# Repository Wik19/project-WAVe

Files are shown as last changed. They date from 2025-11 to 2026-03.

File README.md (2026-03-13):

# project-WAVe: Vibroacoustic Measurement System for Flapping-Wing Drones

## Overview
**project-WAVe** (Wing Acoustic & Vibroacoustic Experiment) is a custom wireless measurement system designed for flapping-wing drones. This repository contains the hardware design, firmware, and software for a high-fidelity data acquisition platform, specifically tailored as a lightweight expansion deck for the [Flapper Nimble+](https://flapper-drones.com/product/flapper-nimble/) platform.

It serves as a foundation for collecting large-scale vibroacoustic datasets required to develop future machine learning-based Fault Detection and Diagnosis (FDD) algorithms.

## Key Features
* **Miniaturized Custom Hardware**: A custom 4-layer PCB (25.2 x 27.3 mm) designed to fit the standard Bitcraze Crazyflie expansion deck footprint.
* **High-Fidelity Inertial Tracking**: LSM6DS3TR-C 6-DOF IMU capturing 3-axis acceleration and angular velocity via SPI.
* **Precision Acoustic Acquisition**: INMP441 digital MEMS microphone via I2S for 24-bit resolution acoustic recordings.
* **Real-Time Wireless Streaming**: ESP32-C3 microcontroller actings as a TCP server, streaming data over 2.45 GHz Wi-Fi.
* **Concurrent Processing**: Efficient use of DMA, dual-buffers, and hardware interrupts for simultaneous data collection and transmission.

## Repository Structure
The project is organized into three technical domains:

### [WAVe-PCB](./WAVe-PCB)
Contains the electronics design files (KiCad).
* **MCU**: ESP32-C3FH4 SoC.
* **Sensors**: LSM6DS3TR-C IMU & INMP441 Microphone.
* **Power**: TPS566238RQFR buck converter for stable 3.3V delivery.

### [data-collection](./data-collection)
Embedded firmware developed using PlatformIO and the ESP-IDF framework.
* Manages low-level task scheduling (FreeRTOS).
* Handles interrupt-driven sensor readings and network transmission.
* Optimized for high-frequency IMU and acoustic data streaming.

### [data-processing](./data-processing)
Python client for real-time data reception and analysis.
* Utilizes TCP sockets to receive high-bandwidth data frames.
* Implements SciPy for real-time parsing, FFT, and STFT spectrogram visualizations.
* Specifically adapted for capturing 3-second IMU frames for diagnostic analysis.

## Experimental Validation
The system has been successfully validated through:
1. **Bench Testing**: Verification of sensor fidelity and wireless throughput.
2. **In-Flight Trials**: Successful capture of distinct cyclostationary vibroacoustic signatures during hover and forward flight maneuvers.
3. **Decoupled Architecture**: High-bandwidth data handling without introducing latency to the drone's primary flight controller.

## Authors
* [Marco Wiktor Santoro](https://github.com/Wik19)
* [Olaf Bukowski](https://github.com/olaf-bukowski)

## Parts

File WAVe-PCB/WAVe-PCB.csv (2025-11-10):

Reference | Qty | Value | DNP | Exclude from BOM | Exclude from Board | Footprint | Datasheet
R13,R14 | 2 | 0R |  |  |  | Resistor_SMD:R_0603_1608Metric | ~
C24 | 1 | 33p |  |  |  | Capacitor_SMD:C_0603_1608Metric | ~
L1 | 1 | 2n |  |  |  | 744786012A:INDC1608X95N | ~
C5,C20 | 2 | 10n |  |  |  | Capacitor_SMD:C_0603_1608Metric | ~
R5 | 1 | 24nH |  |  |  | MHQ1005P24NGTD25:MHQ1005 | https://product.tdk.com/system/files/dam/doc/product/inductor/inductor/smd/catalog/inductor_automotive_high-frequency_mhq1005p_en.pdf
C1,C2,C3,C4,C7,C8,C9,C11,C22,C23,C26,C27 | 12 | 100n |  |  |  | Capacitor_SMD:C_0603_1608Metric | ~
C6,C10,C21 | 3 | 1u |  |  |  | Capacitor_SMD:C_0603_1608Metric | ~
L4 | 1 | 1.5u |  |  |  | 74438357015:74438357015 | ~
C28 | 1 | 10u |  |  |  | Capacitor_SMD:C_0603_1608Metric | ~
C14,C15,C16 | 3 | 22u |  |  |  | Capacitor_SMD:C_0603_1608Metric | ~
C19 | 1 | 47u |  |  |  | Capacitor_SMD:C_0603_1608Metric | ~
R1,R4,R6,R9,R10,R11 | 6 | 10k |  |  |  | Resistor_SMD:R_0603_1608Metric | ~
R16 | 1 | 20k |  |  |  | Resistor_SMD:R_0603_1608Metric | ~
R7 | 1 | 100k |  |  |  | Resistor_SMD:R_0603_1608Metric | ~
L3 | 1 | 1n2 |  |  |  | 744786012A:INDC1608X95N | https://www.mouser.pl/ProductDetail/TDK/MLG1005S1N2BTD25?qs=u4%252BEJ9urDARF5PnqAQUamg%3D%3D
ANT1 | 1 | 2450AT18E0100E |  |  |  | ANTC3216X130N | https://www.mouser.co.za/datasheet/2/611/2450AT18E0100-1666847.pdf
C25 | 1 | 4x 22u |  |  |  | Capacitor_SMD:C_0603_1608Metric | ~
R15 | 1 | 90k9 |  |  |  | Resistor_SMD:R_0603_1608Metric | ~
Y2 | 1 | ABM8-40.000MHZ-B2-T |  |  |  | ABM810000MHZ12D2W | https://abracon.com/Resonators/abm8.pdf
LED1 | 1 | APT1608LSECK_J3-PRV |  |  |  | APT1608CGCK | http://www.kingbrightusa.com/images/catalog/SPEC/APT1608LSECK-J3-PRV.pdf
P1 | 1 | CF_EXP |  |  |  | drone_connector:drone_connector
IC1 | 1 | ESP32-C3FH4 |  |  |  | ESP32-C3FH4:QFN50P500X500X90-33N-D | https://www.espressif.com/sites/default/files/documentation/esp32-c3_datasheet_en.pdf
IC3 | 1 | ICS-43434 |  |  |  | ICS43434 | https://www.digikey.in/en/products/detail/tdk-invensense/ICS-43434/6140298
U1 | 1 | LSM6DS3 |  |  |  | Package_LGA:LGA-14_3x2.5mm_P0.5mm_LayoutBorder3x4y | https://www.st.com/resource/en/datasheet/lsm6ds3tr-c.pdf
SW1,SW2 | 2 | SW_Push |  |  |  | 435151014824:435151014824 | https://www.we-online.com/components/products/datasheet/435151014824.pdf
C12,C13,C17,C18 | 4 | TBD |  |  |  | Capacitor_SMD:C_0603_1608Metric | ~
L2 | 1 | TBD |  |  |  | Inductor_SMD:L_0402_1005Metric | ~
IC2 | 1 | TPS566238RQFR |  |  |  | TPS566238RQFR | https://www.ti.com/lit/ds/symlink/tps566238.pdf?ts=1674445033157
J1 | 1 | USB_Micro-B_Wuerth_614105150721_Vertical_CircularHoles |  |  |  | Connector_USB:USB_Micro-B_Wuerth_614105150721_Vertical_CircularHoles | https://www.mouser.pl/ProductDetail/Wurth-Elektronik/614105150721?qs=a9WhcLg8qCw5r6rjD3973Q%3D%3D

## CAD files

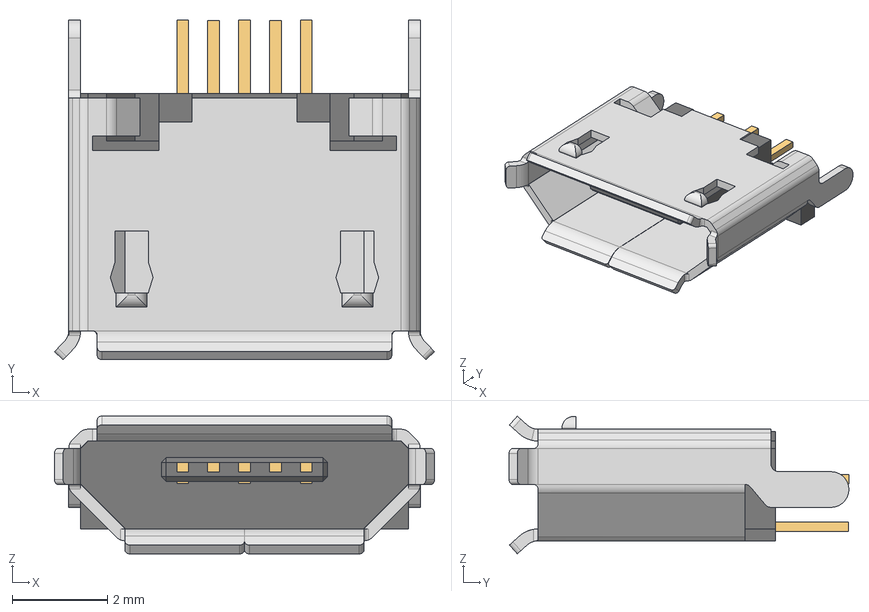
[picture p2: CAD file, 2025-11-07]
WAVe-PCB/components/LIB_614105150721/614105150721/3D/614105150721.stp
8.00 x 7.15 x 2.90 mm
614105150721_Housing
614105150721_Pin1 x 3
614105150721_Pin2 x 2
614105150721_Shielding

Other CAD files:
WAVe-PCB/components/LIB_614105150721/614105150721/Allegro/614105150721.psm
WAVe-PCB/components/LIB_614105150721/614105150721/DEHDL/614105150721/chips/chips.prt

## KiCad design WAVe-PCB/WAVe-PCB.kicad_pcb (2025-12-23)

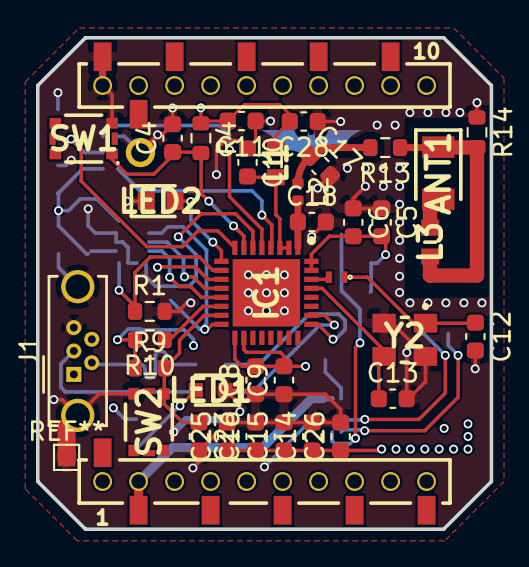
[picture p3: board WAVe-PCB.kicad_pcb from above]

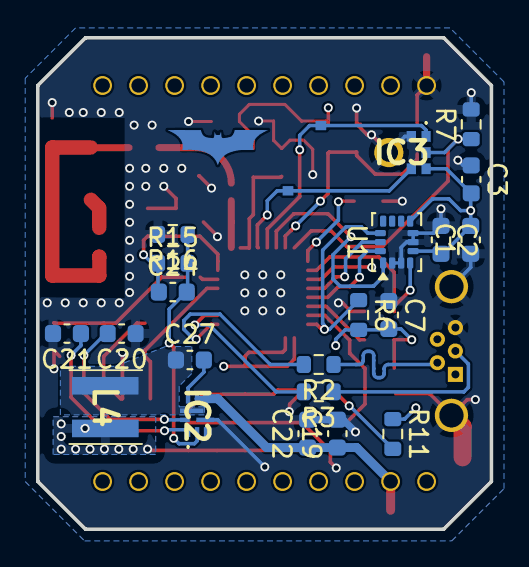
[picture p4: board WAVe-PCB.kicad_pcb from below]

Board: 4 copper layers, 25.2 x 27.3 mm, 58 parts (21 on the bottom side), 33 nets.

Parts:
ANT1: 2450AT18E0100E; ANTC3216X130N
C1, C2, C3, C4, C7, C8, C9, C11, C22, C23, C26, C27: 100n; C_0603_1608Metric
C5, C20: 10n; C_0603_1608Metric
C6, C10, C21: 1u; C_0603_1608Metric
C12, C13, C17, C18: TBD; C_0603_1608Metric
C14, C15, C16: 22u; C_0603_1608Metric
C19: 47u; C_0603_1608Metric
C24: 33p; C_0603_1608Metric
C25: 4x 22u; C_0603_1608Metric
C28: 10u; C_0603_1608Metric
IC1: ESP32-C3FH4; QFN50P500X500X90-33N-D
IC2: TPS566238RQFR
IC3: ICS-43434; ICS43434
J1: USB_Micro-B_Wuerth_614105150721_Vertical_Circular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; USB_Micro-B_Wuerth_614105150721_Vertical_CircularHoles
L1: 2n; INDC1608X95N
L2: TBD; L_0402_1005Metric
L3: 1n2; INDC1608X95N
L4: 1.5u; 74438357015
LED1: APT1608LSECK_J3-PRV; APT1608CGCK
LED2: 150060GS83000; LEDC1608X115N
P1: CF_EXP; drone_connector
R1, R4, R6, R9, R10, R11: 10k; R_0603_1608Metric
R2, R3: 22; R_0603_1608Metric
R5: 24nH; MHQ1005
R7: 100k; R_0603_1608Metric
R13, R14: 0R; R_0603_1608Metric
R15: 90k9; R_0603_1608Metric
R16: 20k; R_0603_1608Metric
SW1, SW2: SW_Push; 435151014824
U1: LSM6DS3; LGA-14_3x2.5mm_P0.5mm_LayoutBorder3x4y
Y2: ABM8-40.000MHZ-B2-T; ABM810000MHZ12D2W

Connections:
+3V3: C1.2, C2.2, C3.2, C5.2, C6.2, C7.2, C8.2, C9.2, C11.2, C14.1, C15.1, C16.1, C24.1, C25.1, C26.1, C28.2, IC1.11 (VDD3P3_RTC), IC1.17 (VDD3P3_CPU), IC1.18 (VDD_SPI), IC1.31 (VDDA_1), IC1.32 (VDDA_2), IC3.5 (VDD), L1.1, L4.2, R4.1, R6.2, R9.1, R10.2, R11.1, R15.1, U1.5 (VDDIO), U1.8 (VDD)
+BATT: C19.1, C22.1, IC2.5 (VIN_1), IC2.6 (VIN_2), P1.19 (VCOM)
/BOOT: C23.1, IC1.15 (GPIO9), R9.2, SW2.1
/CS: IC1.16 (GPIO10), R6.1, U1.12 (CS)
/DO: IC1.6 (GPIO2), U1.1 (SDO/SA0)
/LED_G: IC1.9 (MTMS), LED2.2 (A)
/RESET: C4.1, IC1.7 (CHIP_EN), R4.2, SW1.1
/SCK: IC1.4 (XTAL_32K_P), IC3.4 (SCK)
/SCL: IC1.12 (MTCK), U1.13 (SCL)
/SD: IC1.8 (GPIO3), IC3.6 (SD), R7.1
/SDA: IC1.13 (MTDO), U1.14 (SDA)
/USB_D+: IC1.26 (GPIO19), R3.2
/USB_D-: IC1.25 (GPIO18), R2.2
/WS: IC1.5 (XTAL_32K_N), IC3.1 (WS)
/antenna: C18.1, IC1.1 (LNA_IN), L2.2
/int1: IC1.10 (MTDI), R1.1, U1.4 (INT1)
/xtal_1: C12.1, R5.1, Y2.1 (X1)
/xtal_2: C13.1, IC1.29 (XTAL_N), Y2.3 (X2)
GND: C1.1, C2.1, C3.1, C4.2, C5.1, C6.1, C7.1, C8.1, C9.1, C10.1, C11.1, C12.2, C13.2, C14.2, C15.2, C16.2, C17.2, C18.2, C19.2, C20.1, C21.2, C22.2, C23.2, C25.2, C26.2, C28.1, IC1.33 (EP), IC2.4 (PGND), IC3.2 (LR), IC3.3 (GND), J1.5, J1.6, LED1.1 (K), LED2.1 (K), P1.10 (GND), R1.2, R7.2, R14.1, R16.2, SW1.3, SW2.3, U1.2 (SDX), U1.3 (SCX), U1.6 (GND), U1.7 (GND), Y2.2 (GND_1), Y2.4 (GND_2)
unnamed: ANT1.1 (FEED), L3.2, R13.1, R14.2
unnamed: ANT1.2 (NC), L3.1
unnamed: C17.1, L2.1, R13.2
unnamed: IC1.14 (GPIO8), R10.1
unnamed: C10.2, IC1.2 (VDD3P3_1), IC1.3 (VDD3P3_2), L1.2
unnamed: IC1.30 (XTAL_P), R5.2
unnamed: C27.2, IC2.7 (BST)
unnamed: C24.2, IC2.2 (FB), R15.2, R16.1
unnamed: C20.2, IC2.9 (SS)
unnamed: C27.1, IC2.8 (SW), L4.1
unnamed: C21.1, IC2.1 (VCC)
unnamed: J1.2, R2.1
unnamed: J1.3, R3.1
unnamed: LED1.2 (A), R11.2

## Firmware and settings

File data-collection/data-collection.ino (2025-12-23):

#include <WiFi.h>
#include <Adafruit_LSM6DSOX.h>
#include <Adafruit_Sensor.h>
#include <SPI.h>
#include "driver/i2s.h"
#include <vector>
#include <cstring>

// --- Wi-Fi Configuration ---
const char *ssid = "marco-laptop";
const char *password = "123456789";
const uint16_t serverPort = 8080;

// --- Sensor Pin Definitions ---
#define IMU_CS_PIN 10 //git
#define IMU_SCK_PIN 6 //git
#define IMU_MISO_PIN 2 //git
#define IMU_MOSI_PIN 7 //git

#define I2S_MIC_SERIAL_CLOCK_PIN 0 // git
#define I2S_MIC_WORD_SELECT_PIN 1 //git
#define I2S_MIC_SERIAL_DATA_PIN 3 //git

// --- Interrupt Pin Definition ---
#define IMU_INT_PIN 5 //git 
volatile bool imuDataReady = false;

// --- Sensor Configuration ---
#define IMU_ODR LSM6DS_RATE_416_HZ
#define I2S_SAMPLE_RATE 16000
#define I2S_BITS_PER_SAMPLE I2S_BITS_PER_SAMPLE_32BIT
#define I2S_PORT_NUM I2S_NUM_0
#define MIC_AUDIO_CHUNK_SAMPLES 256

// --- Application State & Buffering Configuration ---
enum AppState {
  AWAITING_CONNECTION,
  AWAITING_COMMAND,
  STREAMING_IMU,
  STREAMING_AUDIO
};
AppState currentState = AWAITING_CONNECTION;

const size_t TARGET_IMU_PACKETS = 3 * 416;

// <<< NEW >>> Define the size of our audio batches
const size_t AUDIO_BATCH_PACKET_COUNT = 50;

// --- Global Objects ---
Adafruit_LSM6DSOX sox;
WiFiServer tcpServer(serverPort);
WiFiClient client;

uint32_t imuPacketCounter = 0;

// --- Binary Packet Structure Definition ---
const uint8_t PACKET_TYPE_IMU = 0x01;
const uint8_t PACKET_TYPE_AUDIO = 0x02;
const uint8_t CMD_REQUEST_IMU = 0x11;
const uint8_t CMD_REQUEST_AUDIO = 0x22;

#pragma pack(push, 1)
struct ImuPacket {
  uint8_t type = PACKET_TYPE_IMU;
  uint32_t packetIndex;
  float accX, accY, accZ;
  float gyroX, gyroY, gyroZ;
};
#pragma pack(pop)

#pragma pack(push, 1)
struct AudioDataPacket {
  uint8_t type = PACKET_TYPE_AUDIO;
  uint32_t timestamp_ms;
  uint16_t num_samples = MIC_AUDIO_CHUNK_SAMPLES;
  int32_t samples[MIC_AUDIO_CHUNK_SAMPLES];
};
#pragma pack(pop)

// --- Data Buffers ---
std::vector<ImuPacket> imuBuffer;
const size_t IMU_BUFFER_CAPACITY = TARGET_IMU_PACKETS;

// <<< NEW >>> Statically allocate our two large audio buffers for the ping-pong mechanism
static AudioDataPacket audioBufferA[AUDIO_BATCH_PACKET_COUNT];
static AudioDataPacket audioBufferB[AUDIO_BATCH_PACKET_COUNT];

// <<< NEW >>> FreeRTOS objects for concurrent streaming
QueueHandle_t audioBufferQueue; // This queue will hold POINTERS to the full buffers
TaskHandle_t audioCollectorTaskHandle;
TaskHandle_t wifiSenderTaskHandle;
volatile bool isStreamingAudio = false; // Flag to control the tasks


// --- Function Prototypes ---
void setup_wifi();
void setup_imu();
void setup_microphone();
void sendImuData();
void clearBuffers();

// --- Interrupt Service Routine (ISR) ---
void IRAM_ATTR imuInterruptHandler() {
  imuDataReady = true;
}

void audioCollectorTask(void *pvParameters) {
  // Start by using Buffer A
  AudioDataPacket* currentBuffer = audioBufferA;

  for (;;) { // Loop forever
    if (isStreamingAudio) {
      // Fill the current buffer with 50 packets
      for (int i = 0; i < AUDIO_BATCH_PACKET_COUNT; i++) {
        size_t bytes_read = 0;
        // Block and wait for a chunk of audio from the I2S driver
        i2s_read(I2S_PORT_NUM, (void*)currentBuffer[i].samples,
                 MIC_AUDIO_CHUNK_SAMPLES * sizeof(int32_t),
                 &bytes_read, portMAX_DELAY);

        // Add a timestamp to this individual packet
        currentBuffer[i].timestamp_ms = millis();
      }

      // Now that the buffer is full, send a POINTER to it to the sender task
      xQueueSend(audioBufferQueue, &currentBuffer, portMAX_DELAY);

      // Immediately switch to the other buffer to start collecting new data (the "pong")
      // This ensures no gap in collection.
      if (currentBuffer == audioBufferA) {
        currentBuffer = audioBufferB;
      } else {
        currentBuffer = audioBufferA;
      }

    } else {
      vTaskDelay(pdMS_TO_TICKS(100)); // Wait if not streaming
    }
  }
}

// <<< NEW >>> Task 2: The Wi-Fi Sender (Consumer)
// This task's only job is to wait for a full buffer and send it.
void wifiSenderTask(void *pvParameters) {
  AudioDataPacket* bufferToSend; // A pointer to hold the buffer we receive from the queue

  for (;;) { // Loop forever
    if (isStreamingAudio && client && client.connected()) {
      // Wait until a pointer to a full buffer appears on the queue
      if (xQueueReceive(audioBufferQueue, &bufferToSend, portMAX_DELAY) == pdPASS) {
        // We received a full buffer! Now, send all 50 packets.
        for (int i = 0; i < AUDIO_BATCH_PACKET_COUNT; i++) {
          client.write((const uint8_t*)&bufferToSend[i], sizeof(AudioDataPacket));
        }
        Serial.printf("Sent audio batch of %d packets.\n", AUDIO_BATCH_PACKET_COUNT);
      }
    } else {
      vTaskDelay(pdMS_TO_TICKS(100)); // Wait if not streaming or not connected
    }
  }
}


// --- Setup Function ---
void setup() {
  Serial.begin(115200);
  while (!Serial) delay(10);
  Serial.println("\nESP32-C3 Sensor Server - Dual Task Ping-Pong");

  imuBuffer.reserve(IMU_BUFFER_CAPACITY);

  pinMode(IMU_INT_PIN, INPUT);
  attachInterrupt(digitalPinToInterrupt(IMU_INT_PIN), imuInterruptHandler, RISING);

  setup_wifi();
  setup_imu();
  setup_microphone();

  // Queue can hold up to 2 pointers (one for each buffer)
  audioBufferQueue = xQueueCreate(2, sizeof(AudioDataPacket*));

  // Create tasks pinned to Core 0. Let Wi-Fi and other system stuff have Core 1 if needed.
  // Collector task has higher priority (2) than Sender task (1)
  xTaskCreatePinnedToCore(audioCollectorTask, "AudioCollector", 4096, NULL, 2, &audioCollectorTaskHandle, 0);
  xTaskCreatePinnedToCore(wifiSenderTask, "WiFiSender", 4096, NULL, 1, &wifiSenderTaskHandle, 0);

  Serial.println("Setup finished. Starting TCP server...");
  tcpServer.begin();
  Serial.printf("TCP server started on port %d\n", serverPort);
  currentState = AWAITING_CONNECTION;
}

// --- Main Loop ---
void loop() {
  if (!client || !client.connected()) {
    if (client) {
      Serial.println("Client disconnected.");
      client.stop();
      isStreamingAudio = false; // Stop streaming tasks if client disconnects
    }
    currentState = AWAITING_CONNECTION;
    client = tcpServer.available();
    if (client) {
      Serial.printf("New client connected: %s. Heap: %u\n", client.remoteIP().toString().c_str(), ESP.getFreeHeap());
      Serial.println("--> State: AWAITING_COMMAND");
      currentState = AWAITING_COMMAND;
    } else {
      vTaskDelay(pdMS_TO_TICKS(10)); // Use vTaskDelay in main loop now
      return;
    }
  }

  switch (currentState) {
    case AWAITING_COMMAND: {
        isStreamingAudio = false; // Ensure tasks are paused
        if (client.available() > 0) {
          uint8_t command = client.read();
          clearBuffers();
          if (command == CMD_REQUEST_IMU) {
            currentState = STREAMING_IMU;
          } else if (command == CMD_REQUEST_AUDIO) {
            xQueueReset(audioBufferQueue); // Empty the queue before starting
            isStreamingAudio = true; // Enable the audio tasks
            currentState = STREAMING_AUDIO;
            Serial.println("Audio streaming started...");
          } else {
            client.stop();
            currentState = AWAITING_CONNECTION;
          }
        }
        break;
      }

    case STREAMING_IMU: {
        if (imuDataReady) {
          imuDataReady = false;
          sensors_event_t accel, gyro, temp;
          sox.getEvent(&accel, &gyro, &temp);
          if (imuBuffer.size() < imuBuffer.capacity()) {
            ImuPacket pkt;
            pkt.packetIndex = ++imuPacketCounter;
            pkt.accX = accel.acceleration.x; pkt.accY = accel.acceleration.y; pkt.accZ = accel.acceleration.z;
            pkt.gyroX = gyro.gyro.x; pkt.gyroY = gyro.gyro.y; pkt.gyroZ = gyro.gyro.z;
            imuBuffer.push_back(pkt);
          }
        }
        if (imuBuffer.size() >= TARGET_IMU_PACKETS) {
          sendImuData();
          imuBuffer.clear();
        }
        break;
      }

    case STREAMING_AUDIO: {
        // The main loop does almost nothing here for audio!
        // The background tasks are doing all the work.
        // We just need to check for a new command to stop streaming.
        if (client.available() > 0) {
          Serial.println("Command received, stopping audio stream.");
          isStreamingAudio = false;
          currentState = AWAITING_COMMAND;
        }
        // A small delay to prevent this loop from starving other tasks
        vTaskDelay(pdMS_TO_TICKS(10));
        break;
      }
    case AWAITING_CONNECTION:
    default:
      vTaskDelay(pdMS_TO_TICKS(10));
      break;
  }
}

// --- Utility Functions ---

void clearBuffers() {
  imuBuffer.clear();
  xQueueReset(audioBufferQueue); // Clear the queue instead of a vector
  imuPacketCounter = 0;
}

void sendImuData() {
  if (!client || !client.connected()) return;
  Serial.printf("Sending %zu IMU packets to client...\n", imuBuffer.size());
  for (const auto& packet : imuBuffer) {
    if (client.write((const uint8_t*)&packet, sizeof(packet)) != sizeof(packet)) {
      client.stop();
      return;
    }
  }
}

// --- Setup Functions (unchanged) ---

void setup_wifi() {
  WiFi.mode(WIFI_STA);
  WiFi.begin(ssid, password);
  Serial.print("Connecting to WiFi");
  for (int attempts = 0; WiFi.status() != WL_CONNECTED && attempts < 30; attempts++) {
    delay(500); Serial.print(".");
  }
  if (WiFi.status() == WL_CONNECTED) {
    Serial.println("\nWiFi connected!");
    Serial.print("IP address: "); Serial.println(WiFi.localIP());
  } else {
    Serial.println("\nFailed to connect. Halting."); while (1) delay(1000);
  }
}

void setup_imu() {
  Serial.println("Setting up IMU (LSM6DSOX)...");
  SPI.begin(IMU_SCK_PIN, IMU_MISO_PIN, IMU_MOSI_PIN, -1);
  if (!sox.begin_SPI(IMU_CS_PIN, &SPI)) {
    Serial.println("Failed to find LSM6DSOX. Halting."); while (1) delay(10);
  }
  Serial.println("LSM6DSOX Found!");
  sox.setAccelRange(LSM6DS_ACCEL_RANGE_16_G);
  sox.setGyroRange(LSM6DS_GYRO_RANGE_2000_DPS);
  sox.setAccelDataRate(IMU_ODR);
  sox.setGyroDataRate(IMU_ODR);

  delay(100);
  sox.configIntOutputs(false, false);
  sox.configInt1(false, false, true, false, false);

  Serial.println("IMU Data Ready Interrupt Enabled on sensor.");
  delay(100);
}

void setup_microphone() {
  Serial.println("Setting up Microphone (INMP441)...");
  i2s_config_t i2s_config = {
    .mode = (i2s_mode_t)(I2S_MODE_MASTER | I2S_MODE_RX), .sample_rate = I2S_SAMPLE_RATE,
    .bits_per_sample = I2S_BITS_PER_SAMPLE, .channel_format = I2S_CHANNEL_FMT_ONLY_LEFT,
    .communication_format = I2S_COMM_FORMAT_STAND_I2S, .intr_alloc_flags = ESP_INTR_FLAG_LEVEL1,
    .dma_buf_count = 8, .dma_buf_len = MIC_AUDIO_CHUNK_SAMPLES,
    .use_apll = false, .tx_desc_auto_clear = false, .fixed_mclk = 0
  };
  i2s_pin_config_t pin_config = {
    .bck_io_num = I2S_MIC_SERIAL_CLOCK_PIN, .ws_io_num = I2S_MIC_WORD_SELECT_PIN,
    .data_out_num = I2S_PIN_NO_CHANGE, .data_in_num = I2S_MIC_SERIAL_DATA_PIN
  };
  i2s_driver_install(I2S_PORT_NUM, &i2s_config, 0, NULL);
  i2s_set_pin(I2S_PORT_NUM, &pin_config);
  i2s_zero_dma_buffer(I2S_PORT_NUM);
  Serial.println("Microphone Setup Complete.");
}

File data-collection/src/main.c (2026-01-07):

#include <stdio.h>
#include <string.h>
#include <sys/param.h>
#include "freertos/FreeRTOS.h"
#include "freertos/task.h"
#include "esp_system.h"
#include "esp_log.h"
#include "nvs_flash.h"

// --- LwIP Includes ---
#include "lwip/err.h"
#include "lwip/sockets.h"
#include "lwip/sys.h"
#include <lwip/netdb.h>

// --- Custom Modules ---
#include "imu_driver.h"
// Assuming you have this file or the function definition available
// #include "wifi_connect.h" 
// If you don't have a header, declare the function extern:
extern void wifi_init_sta(void);

#define PORT 8080
static const char *TAG = "MAIN_APP";

// =============================================================
//                   MAIN SERVER TASK
// =============================================================

static void tcp_server_task(void *pvParameters) {
    char addr_str[128];
    int addr_family = AF_INET;
    int ip_protocol = IPPROTO_IP;
    struct sockaddr_in dest_addr;

    // Buffer for batching: 50 bytes per line * 30 samples approx = 1500 bytes
    char payload[1500]; 
    int payload_offset = 0;
    
    // Batch size: How many samples to group before sending?
    // 416Hz / 20 = ~20 packets per second (much healthier for WiFi)
    const int SAMPLES_PER_BATCH = 20;
    int sample_count = 0;

    imu_data_packet_t data;

    while (1) {
        struct sockaddr_in *dest_addr_ip4 = (struct sockaddr_in *)&dest_addr;
        dest_addr_ip4->sin_addr.s_addr = htonl(INADDR_ANY);
        dest_addr_ip4->sin_family = AF_INET;
        dest_addr_ip4->sin_port = htons(PORT);

        int listen_sock = socket(addr_family, SOCK_STREAM, ip_protocol);
        if (listen_sock < 0) {
            ESP_LOGE(TAG, "Unable to create socket: errno %d", errno);
            vTaskDelay(1000 / portTICK_PERIOD_MS);
            continue;
        }

        // --- OPTIONAL: Enable TCP_NODELAY to disable Nagle's algorithm ---
        int flag = 1;
        setsockopt(listen_sock, IPPROTO_TCP, TCP_NODELAY, &flag, sizeof(flag));
        // ----------------------------------------------------------------

        bind(listen_sock, (struct sockaddr *)&dest_addr, sizeof(dest_addr));
        listen(listen_sock, 1);

        ESP_LOGI(TAG, "Socket listening on port %d...", PORT);

        struct sockaddr_storage source_addr;
        socklen_t addr_len = sizeof(source_addr);
        int sock = accept(listen_sock, (struct sockaddr *)&source_addr, &addr_len);
        
        if (sock >= 0) {
            ESP_LOGI(TAG, "Client connected!");
            
            // Re-apply NODELAY to the accepted socket just in case
            setsockopt(sock, IPPROTO_TCP, TCP_NODELAY, &flag, sizeof(flag));

            xQueueReset(imu_data_queue);
            payload_offset = 0;
            sample_count = 0;

            while (1) {
                // Wait for data
                if (xQueueReceive(imu_data_queue, &data, portMAX_DELAY)) {
                    
                    // Append to buffer instead of sending immediately
                    int written = snprintf(payload + payload_offset, sizeof(payload) - payload_offset, 
                            "%.2f,%.2f,%.2f,%.2f,%.2f,%.2f\n", 
                            data.acc[0] * ACC_SCALE, 
                            data.acc[1] * ACC_SCALE, 
                            data.acc[2] * ACC_SCALE,
                            data.gyro[0] * GYRO_SCALE, 
                            data.gyro[1] * GYRO_SCALE, 
                            data.gyro[2] * GYRO_SCALE
                    );

                    if (written > 0) {
                        payload_offset += written;
                        sample_count++;
                    }

                    // Send only when we have enough samples OR the buffer is getting full
                    if (sample_count >= SAMPLES_PER_BATCH || payload_offset > (sizeof(payload) - 100)) {
                        
                        int err = send(sock, payload, payload_offset, 0);
                        if (err < 0) {
                            ESP_LOGE(TAG, "Error occurred during sending: errno %d", errno);
                            break; 
                        }
                        
                        // Reset buffer
                        payload_offset = 0;
                        sample_count = 0;
                    }
                }
            }

            shutdown(sock, 0);
            close(sock);
            ESP_LOGI(TAG, "Client disconnected");
        }
        close(listen_sock);
    }
}

// =============================================================
//                       APP MAIN
// =============================================================
void app_main(void) {
    // 1. NVS Init
    esp_err_t ret = nvs_flash_init();
    if (ret == ESP_ERR_NVS_NO_FREE_PAGES || ret == ESP_ERR_NVS_NEW_VERSION_FOUND) {
      ESP_ERROR_CHECK(nvs_flash_erase());
      nvs_flash_init();
    }

    // 2. Init Modules
    // Order matters: Init IMU first to create the Queue.
    init_imu();
    wifi_init_sta();

    // 3. Start Server
    xTaskCreate(tcp_server_task, "tcp_server", 4096, NULL, 5, NULL);
}

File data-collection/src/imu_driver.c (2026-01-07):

#include "imu_driver.h"
#include <string.h>
#include "driver/spi_master.h"
#include "driver/gpio.h"
#include "freertos/FreeRTOS.h"
#include "freertos/task.h"
#include "freertos/semphr.h"
#include "esp_log.h"

static const char *TAG = "IMU_DRIVER";

// --- PINS & REGISTERS ---
#define PIN_CS      10
#define PIN_CLK     6
#define PIN_MISO    2
#define PIN_MOSI    7
#define PIN_IMU_INT 5   // Interrupt Pin

// Common ST IMU Registers (LSM6DS series)
#define REG_INT1_CTRL   0x0D
#define REG_WHO_AM_I    0x0F
#define REG_CTRL1_XL    0x10
#define REG_CTRL2_G     0x11
#define REG_CTRL3_C     0x12
#define REG_OUTX_L_G    0x22

// --- SCALING FACTORS ---
const float ACC_SCALE  = 0.488f / 1000.0f * 9.80665f; 
const float GYRO_SCALE = 70.0f  / 1000.0f * 0.017453f; 

// --- GLOBALS ---
static spi_device_handle_t spi;
static SemaphoreHandle_t s_imu_data_ready_sem = NULL;
QueueHandle_t imu_data_queue = NULL; // The queue accessible by main.c

// --- SPI HELPER ---
static void write_register(uint8_t reg, uint8_t value) {
    uint8_t tx_data[2] = { reg & 0x7F, value };
    spi_transaction_t t = { .length = 16, .tx_buffer = tx_data };
    ESP_ERROR_CHECK(spi_device_transmit(spi, &t));
}

// --- INTERRUPT SERVICE ROUTINE (ISR) ---
static void IRAM_ATTR imu_gpio_isr_handler(void* arg)
{
    BaseType_t xHigherPriorityTaskWoken = pdFALSE;
    xSemaphoreGiveFromISR(s_imu_data_ready_sem, &xHigherPriorityTaskWoken);
    if (xHigherPriorityTaskWoken) {
        portYIELD_FROM_ISR();
    }
}

// --- INTERNAL READ FUNCTION ---
// static void read_all_sensors(imu_data_packet_t *packet) {
//     uint8_t tx_buf[13] = {0};
//     tx_buf[0] = REG_OUTX_L_G | 0x80; // Read bit + address
//     uint8_t rx_buf[13] = {0};
    
//     spi_transaction_t t = { .length = 8 * 13, .tx_buffer = tx_buf, .rx_buffer = rx_buf };
//     ESP_ERROR_CHECK(spi_device_transmit(spi, &t));

//     // Parse bytes into the packet struct
//     packet->gyro[0] = (int16_t)((rx_buf[2] << 8) | rx_buf[1]);
//     packet->gyro[1] = (int16_t)((rx_buf[4] << 8) | rx_buf[3]);
//     packet->gyro[2] = (int16_t)((rx_buf[6] << 8) | rx_buf[5]);
//     packet->acc[0]  = (int16_t)((rx_buf[8] << 8) | rx_buf[7]);
//     packet->acc[1]  = (int16_t)((rx_buf[10] << 8) | rx_buf[9]);
//     packet->acc[2]  = (int16_t)((rx_buf[12] << 8) | rx_buf[11]);
// }

static void read_all_sensors(imu_data_packet_t *packet) {
    // FIX: Define buffers as static and 4-byte aligned for DMA
    // DMA requires buffers to be in DRAM and Word-Aligned.
    static uint8_t tx_buf[16] __attribute__((aligned(4))) = {0};
    static uint8_t rx_buf[16] __attribute__((aligned(4))) = {0};

    // Clear buffers (optional but good safety)
    memset(tx_buf, 0, sizeof(tx_buf));
    memset(rx_buf, 0, sizeof(rx_buf));

    tx_buf[0] = REG_OUTX_L_G | 0x80; // Read bit + address

    // Transaction configuration
    spi_transaction_t t = {
        .length = 8 * 13,   // 13 bytes total transaction
        .tx_buffer = tx_buf,
        .rx_buffer = rx_buf
    };
    
    ESP_ERROR_CHECK(spi_device_transmit(spi, &t));

    // Parse bytes into the packet struct
    // The previous logic remains the same
    packet->gyro[0] = (int16_t)((rx_buf[2] << 8) | rx_buf[1]);
    packet->gyro[1] = (int16_t)((rx_buf[4] << 8) | rx_buf[3]);
    packet->gyro[2] = (int16_t)((rx_buf[6] << 8) | rx_buf[5]);
    packet->acc[0]  = (int16_t)((rx_buf[8] << 8) | rx_buf[7]);
    packet->acc[1]  = (int16_t)((rx_buf[10] << 8) | rx_buf[9]);
    packet->acc[2]  = (int16_t)((rx_buf[12] << 8) | rx_buf[11]);
}

// --- DRIVER TASK ---
void imu_task(void *pvParameters) {
    imu_data_packet_t packet;

    while(1) {
        // Wait indefinitely for the Interrupt Semaphore
        if(xSemaphoreTake(s_imu_data_ready_sem, portMAX_DELAY) == pdTRUE) {
            
            // Read data from SPI
            read_all_sensors(&packet);

            // Send to Queue (Don't block if full, just overwrite/drop)
            xQueueSend(imu_data_queue, &packet, 0);
        }
    }
}

// --- INITIALIZATION ---
void init_imu() {
    // 1. Initialize Queue
    // imu_data_queue = xQueueCreate(10, sizeof(imu_data_packet_t));
    imu_data_queue = xQueueCreate(128, sizeof(imu_data_packet_t));

    // 2. SPI Bus Init
    spi_bus_config_t buscfg = {
        .miso_io_num = PIN_MISO, .mosi_io_num = PIN_MOSI, .sclk_io_num = PIN_CLK,
        .quadwp_io_num = -1, .quadhd_io_num = -1, .max_transfer_sz = 32
    };
    ESP_ERROR_CHECK(spi_bus_initialize(SPI2_HOST, &buscfg, SPI_DMA_CH_AUTO));

    spi_device_interface_config_t devcfg = {
        .clock_speed_hz = 10 * 1000 * 1000, .mode = 0,
        .spics_io_num = PIN_CS, .queue_size = 1,
    };
    ESP_ERROR_CHECK(spi_bus_add_device(SPI2_HOST, &devcfg, &spi));

    // 3. Semaphore & GPIO Init
    s_imu_data_ready_sem = xSemaphoreCreateBinary();

    gpio_config_t io_conf = {};
    io_conf.intr_type = GPIO_INTR_POSEDGE; // Rising edge
    io_conf.pin_bit_mask = (1ULL << PIN_IMU_INT);
    io_conf.mode = GPIO_MODE_INPUT;
    io_conf.pull_down_en = 0;
    io_conf.pull_up_en = 0; 
    gpio_config(&io_conf);

    gpio_install_isr_service(0);
    gpio_isr_handler_add(PIN_IMU_INT, imu_gpio_isr_handler, NULL);

    // 4. Configure Sensor
    write_register(REG_CTRL3_C, 0x01); // Reset
    vTaskDelay(20 / portTICK_PERIOD_MS);
    
    write_register(REG_CTRL3_C, 0x44); // Block Data Update
    write_register(REG_CTRL1_XL, 0x64); // Accel 416Hz
    write_register(REG_CTRL2_G,  0x6C); // Gyro 416Hz

    // Enable Hardware Interrupt on Pin INT1 for Gyro Data Ready
    write_register(REG_INT1_CTRL, 0x02); 

    ESP_LOGI(TAG, "IMU Initialized with Interrupts");

    // 5. Start Driver Task
    xTaskCreate(imu_task, "imu_task", 4096, NULL, 10, NULL);
}

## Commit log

2025-11-07 added new microphone
    [AFRO_term_design.csv, AFRO_term_design.kicad_pcb, AFRO_term_design.kicad_sch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]
2025-11-07 finish connecting, add decoupling capacitors on pcb
    [614105150721.psm, 614105150721.stp, EDI2CAP.CFG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]
2025-11-07 changed name of project, fixed main issues, waiting for final confirmation
    [614105150721.psm, 614105150721.stp, AFRO_term_design.kicad_pcb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]
2025-11-10 added mcu led & minor adjustments
    [WAVe-PCB.csv, WAVe-PCB.kicad_pcb, WAVe-PCB.kicad_sch]
2025-11-11 Naprawa przetwornicy zasilajacej, dodanie rezystorow na linie D+ D-, ogolna naprawa polaczen na plytce i debug
    [WAVe-PCB.kicad_pcb, WAVe-PCB.kicad_sch]
2025-12-23 fix ESP code, starting circuit redesign
    [WAVe-PCB.kicad_pcb, WAVe-PCB.kicad_sch]
2025-12-23 finish organizing the new connections between sub-schematics
    [Antenna.kicad_sch, Connectors.kicad_sch, PowerSupply.kicad_sch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]
2025-12-25 connected hierarchical schematics
    [Antenna.kicad_sch, Connectors.kicad_sch, PowerSupply.kicad_sch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]
2026-01-04 split main.c file into multiple, organized, files. Can't check if they work on the board yet
2026-01-12 python script adapted to capturing 3s imu frames from current .c code
